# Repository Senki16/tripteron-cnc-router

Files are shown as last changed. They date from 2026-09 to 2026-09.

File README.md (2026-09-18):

# Tripteron CNC Router — 3-PRRR Parallel Machining Table

Design, drawings and complete engineering verification of a three-degree-of-freedom
translational parallel machine (Tripteron) used as a CNC router.

**IM0240 Machine Design I — Universidad EAFIT, Mechanical Engineering**

**Group 2:** David Amell Osorio · Ronny Antonio Bueno · Juan José García · Germán Gabriel Riaño Barrera · Sebastián Rincón Martínez · Juan Manuel Rodríguez Duque · David Zuluaga Henao
**Course lecturer:** Juan Andrés Gallego Sánchez
**Delivered:** 11 February 2024 (proposal) · 3 March 2024 (drawings) · 25 May 2024 (calculations)

<p align="center">
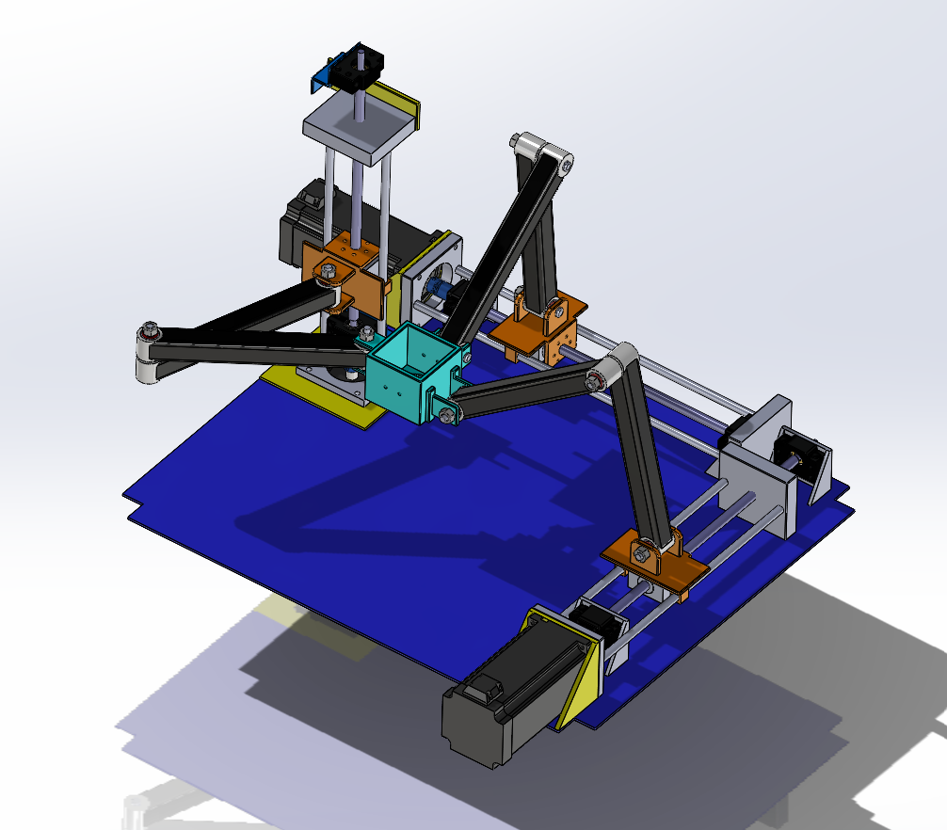
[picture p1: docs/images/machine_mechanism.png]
Tripteron mechanism: three PRRR legs on the work table
  
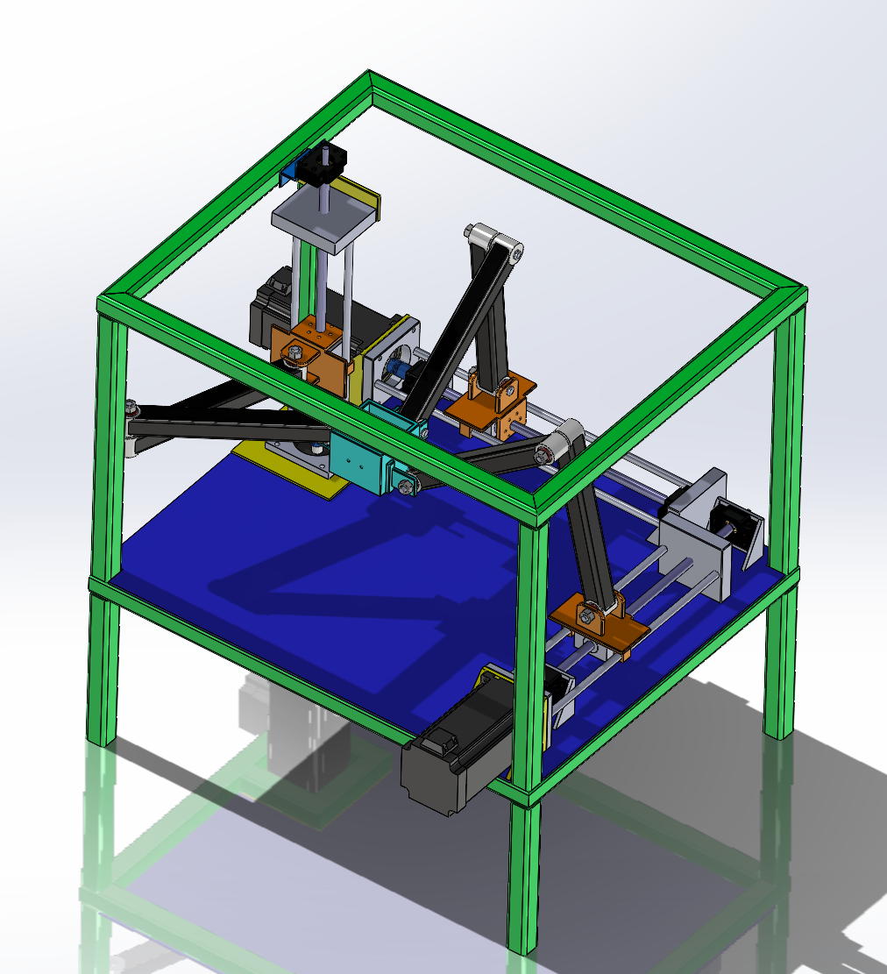
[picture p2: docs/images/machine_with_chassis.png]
Complete machine inside the welded chassis
  
</p>
<p align="center"><em>The 3-PRRR mechanism on the work table, and the complete machine inside its welded frame.</em></p>

---

## What this machine is

The Tripteron is a parallel manipulator with three identical **PRRR** legs: one prismatic
joint driven by a lead screw followed by three revolute joints with parallel axes. The
three prismatic axes are mutually orthogonal.

Its defining property is that it is **fully decoupled**: actuator *i* moves the tool along
axis *i* only, so the machine behaves like a cartesian router while being built as a
parallel mechanism. Its workspace is a perfect cube and its controller needs no coordinate
transformation. Both properties are proved numerically in the calculation report.

| Specification | Value |
|---|---|
| Degrees of freedom | 3 translations (no rotation) |
| Workspace | 200 mm cube — 8.615 dm³ |
| Link lengths | 240 mm (proximal and distal) |
| Stroke per axis | 200 mm |
| Feed rate | 10 mm/s |
| Cutting force (design) | [80, 80, −120] N |
| Drive | Ø8 mm trapezoidal lead screw, p = 2 mm, 4 starts (lead 8 mm) |
| Motor | NEMA 34 86HB250 closed loop, 4.5 N·m |
| Frame | Welded steel tube, alloy steel Sy = 620 MPa |

## Headline results

<p align="center">
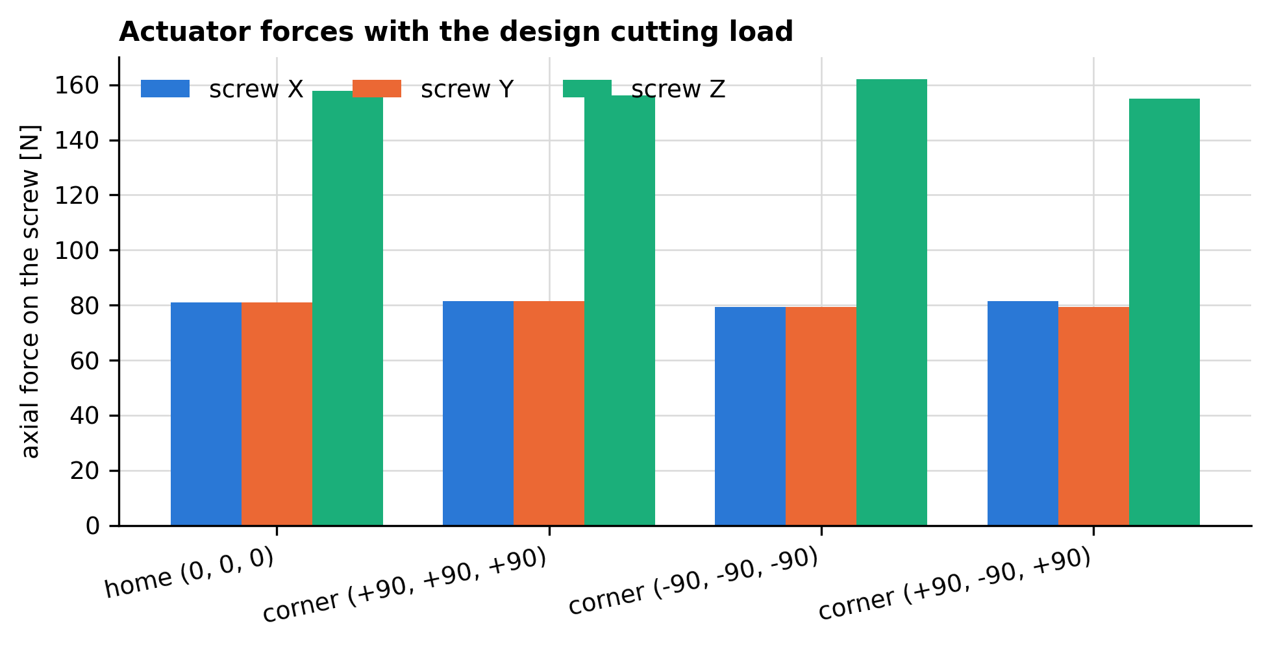
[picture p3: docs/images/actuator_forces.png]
Actuator forces across the workspace
  
</p>
<p align="center">
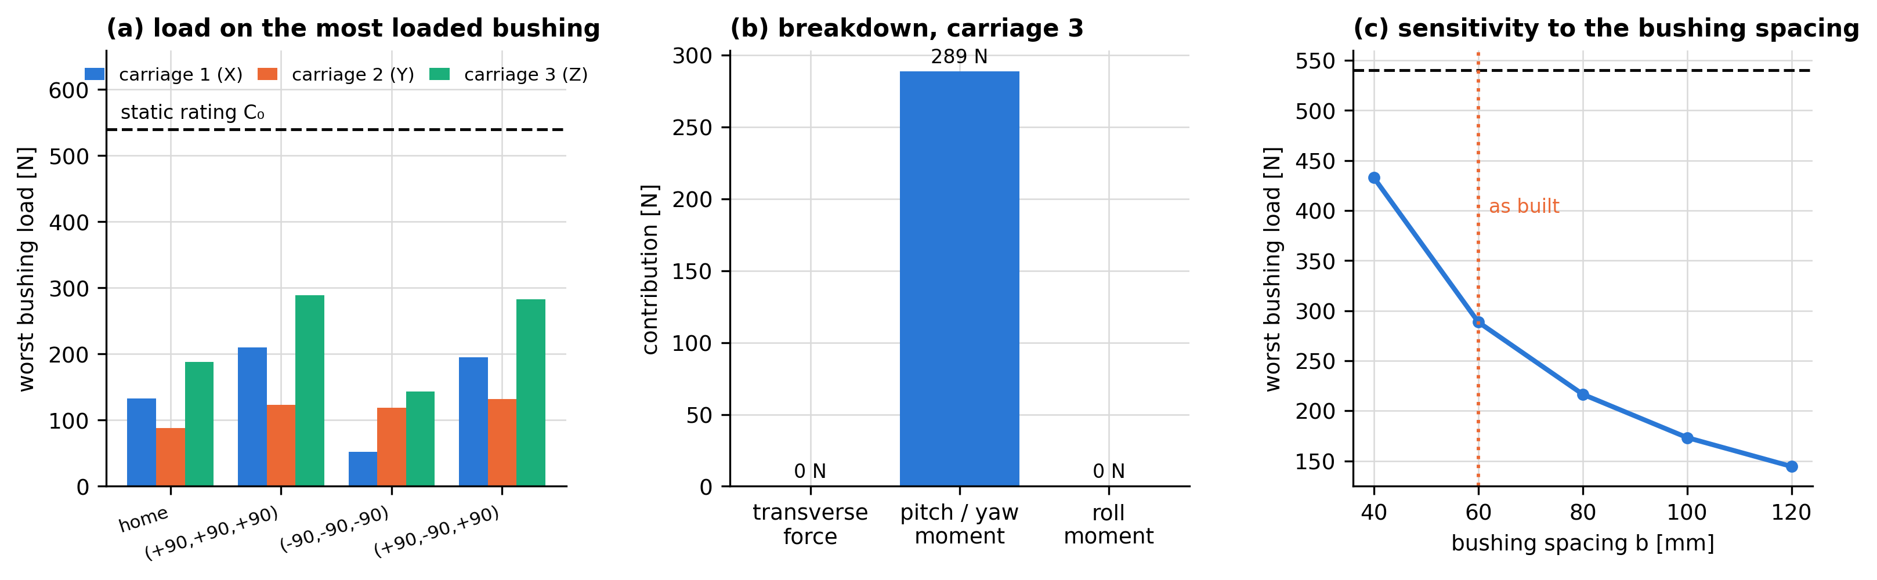
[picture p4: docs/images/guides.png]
Linear guide verification
  
</p>

| Verification | Result | Margin |
|---|---|---|
| Kinematic model | Newton–Raphson residual < 8·10⁻¹¹ mm | matches closed form to 10⁻¹³ mm |
| Design actuator load | **162.0 N** (worst pose, vertical axis) | varies only 4.5 % over the workspace |
| Arm bending stress | 26.1 MPa | SF 9.6 vs AISI 1020 |
| Lead screw, von Mises | 14.3 MPa | SF 25.8 |
| Lead screw, buckling | Pcr = 519.9 N (Euler) | **SF 3.21 — governing criterion** |
| Screw efficiency | 64.1 % | not self-locking → brake required on Z |
| Chassis FEA, stress | 9.36 MPa | SF 66 |
| Chassis FEA, deflection | 0.102 mm | the limiting number for accuracy |
| Guide bushings | 289 N on the worst bushing | **SF 1.87 — the tightest margin in the machine** |
| Guide rods | 8.7 MPa, 0.154 mm deflection | SF 40; more compliant than the whole frame |
| Chassis FEA, buckling | load factor 2238 | irrelevant at this load |

## Repository layout

```
01_Delivery1_Proposal/             Design proposal: requirements, PDS, architecture selection
02_Delivery2_Drawings/             Drawing package: English cover, index and the 35 drawing sheets
    sheets/                        the sheets as PNG (13 redrawn in English, 22 as issued)
03_Delivery3_Calculation_Report/   Calculation report: kinematics, statics, screw, FEA
04_Calculations/                   Python package that produces every number and figure
    tripteron/                     parameters, kinematics, statics, power_screw, fea_postprocess
    data/fea_exports/              nodal data exported from SolidWorks Simulation
    results/                       CSV + summary.json regenerated by run_all.py
    figures/                       PNG figures regenerated by run_all.py
05_CAD/
    Source_Models/                 SolidWorks parts, assemblies and drawings, by group
    Archives/                      large .zip/.rar exports (kept locally, not versioned)
06_Reference/                      Motor datasheets, component dimensions, course material
07_Media/                          Video of the machine running
docs/images/                       Images used by this README
```

## Reproducing the calculations

Everything in the calculation report is generated by code. From `04_Calculations/`:

```bash
python run_all.py
```

The script creates its own virtual environment on first run, installs the dependencies and
writes:

- `results/*.csv` and `results/summary.json` — every number quoted in the report
- `figures/*.png` — every figure of the report

### Modules

| Module | Contents |
|---|---|
| `tripteron/parameters.py` | All machine data in one place: geometry, masses, materials, loads |
| `tripteron/kinematics.py` | Loop-closure constraints, Jacobian, J̇, Newton–Raphson solver, closed-form inverse kinematics, trajectories, workspace |
| `tripteron/statics.py` | 60×63 rigid-body equilibrium system, minimum-norm solution, virtual-work actuator forces, arm stresses |
| `tripteron/power_screw.py` | Torque, efficiency, self-locking, stresses, Euler/Johnson column check |
| `tripteron/guides.py` | Bushing loads, rod stress and deflection of the carriages, sensitivity to the bushing spacing |
| `tripteron/fea_postprocess.py` | Post-processing of the SolidWorks Simulation exports |
| `run_all.py` | Runs the four studies and writes results and figures |

## License

Academic work produced for IM0240 at Universidad EAFIT, first semester 2024.
Shared for reference.

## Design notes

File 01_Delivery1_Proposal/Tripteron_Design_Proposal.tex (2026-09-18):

%==============================================================================
%  TRIPTERON - Delivery 1 : Design proposal (corrected English edition)
%  IM0240 Machine Design I - Universidad EAFIT
%==============================================================================
\documentclass[11pt]{article}
\usepackage[english]{babel}
\usepackage[utf8]{inputenc}
\usepackage{lmodern}
\usepackage[T1]{fontenc}
\usepackage{amsmath,amssymb,bm}
\usepackage{graphicx}
\usepackage{booktabs}
\usepackage{longtable}
\usepackage{array}
\usepackage{placeins}
\usepackage{lastpage}
\usepackage{enumitem}
\usepackage{siunitx}
\usepackage{tikz}
\usetikzlibrary{arrows.meta,positioning,shapes.geometric,calc}
\usepackage[table]{xcolor}
\usepackage[left=2.3cm,right=2.3cm,top=3.2cm,bottom=2.5cm]{geometry}
\usepackage{fancyhdr}
\usepackage[hidelinks]{hyperref}
\usepackage{titlesec}
\sisetup{detect-all, per-mode=symbol}

\definecolor{eafitblue}{HTML}{16436f}
\definecolor{lightgray}{HTML}{f0efe9}

\titleformat{\section}{\normalfont\large\bfseries\color{eafitblue}}{\thesection.}{0.6em}{}[{\titlerule[0.6pt]}]
\titleformat{\subsection}{\normalfont\normalsize\bfseries}{\thesubsection.}{0.6em}{}
\setlength{\parskip}{4pt}
\setlength{\parindent}{0pt}

\pagestyle{fancy}\fancyhf{}
\renewcommand{\headrulewidth}{0.4pt}
\fancyhead[L]{\small\textsc{Tripteron CNC router -- Design proposal}}
\fancyhead[R]{\small IM0240 Machine Design I}
\fancyfoot[C]{\small\thepage\ / \pageref{LastPage}}

\begin{document}

%------------------------------------------------------------------ cover
\thispagestyle{empty}
\begin{center}
\vspace*{1cm}
{\Large\scshape Universidad EAFIT}\\[3pt]
{\large School of Applied Sciences and Engineering}\\[3pt]
{\large Department of Mechanical Engineering}\\[3pt]
{\large IM0240 -- Machine Design I}\\[1.8cm]

{\color{eafitblue}\rule{\textwidth}{1.4pt}}\\[12pt]
{\huge\bfseries Design proposal for a}\\[6pt]
{\huge\bfseries CNC router machine}\\[10pt]
{\LARGE Tripteron 3-PRRR architecture}\\[10pt]
{\large\bfseries Delivery 1 -- Corrected English edition}\\[8pt]
{\color{eafitblue}\rule{\textwidth}{1.4pt}}\\[2cm]

{\large\bfseries Group 2}\\[8pt]
{\large David Amell Osorio}\\[4pt]
{\large Ronny Antonio Bueno}\\[4pt]
{\large Juan Jos\'e Garc\'ia}\\[4pt]
{\large Germ\'an Gabriel Ria\~no Barrera}\\[4pt]
{\large Sebasti\'an Rinc\'on Mart\'inez}\\[4pt]
{\large Juan Manuel Rodr\'iguez Duque}\\[4pt]
{\large David Zuluaga Henao}\\[1.4cm]

{\large\bfseries Course lecturer}\\[8pt]
{\large Juan Andr\'es Gallego S\'anchez}

\vfill
{\large Medell\'in, Colombia -- 11 February 2024}
\end{center}

\clearpage
\tableofcontents
\clearpage

%==============================================================================
\section{Introduction}
%==============================================================================

Within the Machine Design course, the assignment is to conceive, design and build a CNC
router that satisfies a specific set of technical requirements. The goal is a machine
that, using the concepts studied in the course, can be adapted to the manufacturing
processes where light routing and engraving are needed.

This document is the first delivery of the project. It defines the problem, surveys the
state of the art, establishes the requirements and the product design specification,
compares the mechanism architectures that could satisfy them and justifies the
architecture that was selected: a \textbf{Tripteron}, a three-degree-of-freedom
translational parallel machine with three PRRR legs actuated by power screws.

This is a corrected and restructured English edition of the original proposal. The
technical content of the original has been preserved; the errors identified in it are
listed and corrected in Section~\ref{sec:corrections}.

%==============================================================================
\section{Brief}
%==============================================================================

\subsection{What is a router machine?}

A CNC router is an automated machine that uses computer numerical control to cut, carve or
engrave materials such as wood, plastic, metal and composites. It works with a rotating
cutting tool --- an end mill --- whose path is controlled by a program. Because the
process is both precise and repeatable, routers are a basic tool in manufacturing and
design workshops.

\subsection{How does it work?}

The tool moves in a three-dimensional coordinate system driven by three motors. The
operator's controller commands the motors so that the tool sweeps the programmed path
inside the working volume. Each motor drives one power screw, and each power screw moves
one axis of the machine.

\subsection{Which materials are viable for its construction?}

Different parts call for different materials:

\begin{center}
\begin{tabular}{@{}l>{\raggedright\arraybackslash}p{4.0cm}>{\raggedright\arraybackslash}p{8.4cm}@{}}
\toprule
\textbf{Part} & \textbf{Material} & \textbf{Reason} \\
\midrule
External enclosure & PVC or wood & Carries no significant load; low cost, easy to shape \\
Structural frame   & Steel or aluminium & Carries the machining loads and the weight of the drives \\
Mechanism (links, screws) & Steel & Stiffness and wear resistance govern the accuracy \\
\bottomrule
\end{tabular}
\end{center}

%==============================================================================
\section{Objectives}
%==============================================================================

\subsection{General objective}

Design and build a numerically controlled router able to cut at least \SI{1}{\milli\metre}
of depth in a range of materials, making the best use of the available materials,
manufacturing processes and aesthetics.

\subsection{Specific objectives}

\begin{itemize}[leftmargin=*]
  \item Define the flows through the machine --- the inputs it needs and the outputs it
        must deliver --- so that the concept is built on a solid functional basis.
  \item Develop a support structure that guarantees stable operation, minimising
        vibration and avoiding buckling under the weight of the equipment.
  \item Design a machine that meets the client's expectations in appearance, design and
        aesthetics, so that the result is attractive from the user's point of view.
  \item Plan the specific requirements needed to satisfy the client, ensuring the
        technical and functional feasibility of the project.
  \item Select a kinematic chain and a mechanism that suit both the client's needs and an
        efficient development process, guaranteeing adequate performance.
\end{itemize}

%==============================================================================
\section{State of the art}
%==============================================================================

\subsection{CNC machines}

A CNC (computer numerical control) machine removes the human factor from the trajectory of
the tool: the cut is performed automatically by a computer that feeds numerical
coordinates to the machine, which is what makes millimetre and sub-millimetre precision
repeatable.

\subsection{Motion control}

The motion of a CNC machine is controlled by software that interprets G-code. The general
process is:

\begin{enumerate}[leftmargin=*]
  \item \textbf{Model design.} The part is modelled in 3D with a CAD package.
  \item \textbf{G-code generation.} A CAM package converts the model into the G-code that
        specifies tool movements, cutting speeds and tooling.
  \item \textbf{Transfer.} The program is transferred to the machine over a USB drive or a
        network connection.
  \item \textbf{Set-up.} The tool is mounted, the stock is clamped and the cutting
        parameters --- feed rate and spindle speed --- are configured.
  \item \textbf{Execution.} The controller interprets the G-code and moves the axes
        accordingly, producing the part.
\end{enumerate}

\subsection{The CNC program}

A CNC program is a set of coded instructions written mainly in G-code, complemented by M,
S and T codes depending on the functions the machine offers.

\subsection{Types of CNC machines}

\begin{center}
\begin{tabular}{@{}l>{\raggedright\arraybackslash}p{10.7cm}@{}}
\toprule
\textbf{Criterion} & \textbf{Classes} \\
\midrule
By function & Milling machines, lathes, drilling machines, plasma cutters, grinders. \\
By motion   & \emph{Point to point}: the stock and the tool are positioned and held while
              the cutter completes the operation, then retracted.
              \emph{Contouring}: the tool follows the contour of the part along a
              continuous path. \\
By number of axes & 2 axes; 2.5 axes (the three axes move, but $x$ and $y$ position first
              and only then does $z$ work); 3 axes; 4 axes (3 axes plus one rotation,
              $A$ or $B$); 5 axes (3 axes plus two rotations, $A$ and $B$). \\
\bottomrule
\end{tabular}
\end{center}

The machine of this project is a \textbf{3-axis contouring router}.

\subsection{Applications}

Manufacture of metal and plastic parts; cutting and engraving of wood, metal, plastic and
stone for signage, architectural models and artistic engraving; prototyping and mass
production of identical parts; medical devices, prostheses and surgical instrument
components; and, on machines equipped for it, additive manufacturing.

\subsection{Key components}

\begin{description}[leftmargin=0pt,style=nextline]
  \item[Power screw] A mechanical device that converts rotary into linear motion. A
        threaded screw engages a nut with an internal thread; turning the screw
        translates the nut along its axis. It is the element that turns the rotation of
        the motor into the feed of the axis, and it is sized in Delivery~3.
  \item[NEMA 34 stepper motor] A NEMA standard frame size, roughly \SI{86}{\milli\metre}
        across the body, known for high torque. It is used in industrial CNC machines,
        large-format 3D printers and automation equipment. The closed-loop 86HB250 variant
        selected for this project delivers \SI{4.5}{\newton\metre} of holding torque.
  \item[End mill] The rotating cutting tool. A sharpened metal tip turns at high speed and
        removes material on contact. End mills are interchangeable and are chosen
        according to the material and the finish required.
\end{description}

%==============================================================================
\section{User definition}
%==============================================================================

The user of the router is someone experienced with cutting equipment who is looking for a
versatile, easy to operate and affordable machine. The intended duty is light cutting
without extreme demands, in a workshop with a mains supply. The machine is to be operated
by people of at least 18 years of age.

%==============================================================================
\section{Conceptual design}
%==============================================================================

\subsection{Requirements imposed by the course}

\begin{itemize}[leftmargin=*,nosep]
  \item A cutting machine (router) with \textbf{3 degrees of freedom}.
  \item The machine \textbf{may not} be a cartesian system built from prismatic pairs in
        series.
  \item The degrees of freedom must be \textbf{coupled}, i.e.\ the architecture must be a
        parallel one.
  \item The prismatic pairs must be \textbf{actuated by power screws}.
  \item The machine may be spatial (linear delta or Tripteron) or planar.
  \item It must be able to cut at least \SI{1}{\milli\metre} deep in aluminium, copper,
        brass or nylon.
\end{itemize}

\subsection{Technical design requirements}

\begin{center}
\begin{tabular}{@{}l>{\raggedright\arraybackslash}p{10.4cm}@{}}
\toprule
\textbf{Requirement} & \textbf{Definition} \\
\midrule
Feed rate   & Constant routing speed of approximately \SI{10}{\milli\metre\per\second}. \\
Accuracy    & Path error not greater than \SI{1}{\milli\metre}. \\
Cutting capability & Able to route wood, aluminium, copper, brass and nylon to a depth of at least \SI{1}{\milli\metre}. \\
Safety      & The machine must not put the operator at risk during operation. \\
Control     & The operator must have buttons or instruments to start and stop the process. \\
Energy and information & The machine must carry a control system that transmits accurate
              process information while a stable power supply is guaranteed. \\
\bottomrule
\end{tabular}
\end{center}

\subsection{Black box}

The black box states \emph{what} the machine does without saying \emph{how}: the three
flows --- material, energy and information --- that cross its boundary.

\begin{figure}[htbp]\centering
\begin{tikzpicture}[font=\small,node distance=6mm,
  flow/.style={-{Latex[length=2.5mm]},thick}]
\node[draw,fill=lightgray,minimum width=5.4cm,minimum height=3.2cm,align=center,
      rounded corners=2pt,thick] (bb)
      {\bfseries Route the\\\bfseries workpiece};
\node[left=3.0cm of bb.west,anchor=east,align=right] (in) {};
\draw[flow] ($(bb.west)+(-3.0,0.9)$) -- node[above,font=\scriptsize]{raw stock} ($(bb.west)+(0,0.9)$);
\draw[flow] ($(bb.west)+(-3.0,0.0)$) -- node[above,font=\scriptsize]{electrical energy} ($(bb.west)+(0,0.0)$);
\draw[flow] ($(bb.west)+(-3.0,-0.9)$) -- node[above,font=\scriptsize]{part program (G-code)} ($(bb.west)+(0,-0.9)$);
\draw[flow] ($(bb.east)+(0,0.9)$) -- node[above,font=\scriptsize]{routed part} ($(bb.east)+(3.0,0.9)$);
\draw[flow] ($(bb.east)+(0,0.0)$) -- node[above,font=\scriptsize]{chips, heat, noise} ($(bb.east)+(3.0,0.0)$);
\draw[flow] ($(bb.east)+(0,-0.9)$) -- node[above,font=\scriptsize]{process status} ($(bb.east)+(3.0,-0.9)$);
\end{tikzpicture}
\caption{Black box of the router: material, energy and information flows.}
\end{figure}

\subsection{Functional structure}

The functional structure --- the ``transparent box'' --- decomposes the overall function
into the elementary functions that the machine must perform, which is what allows the
concept to be generated function by function instead of by copying an existing machine.

\begin{figure}[htbp]\centering
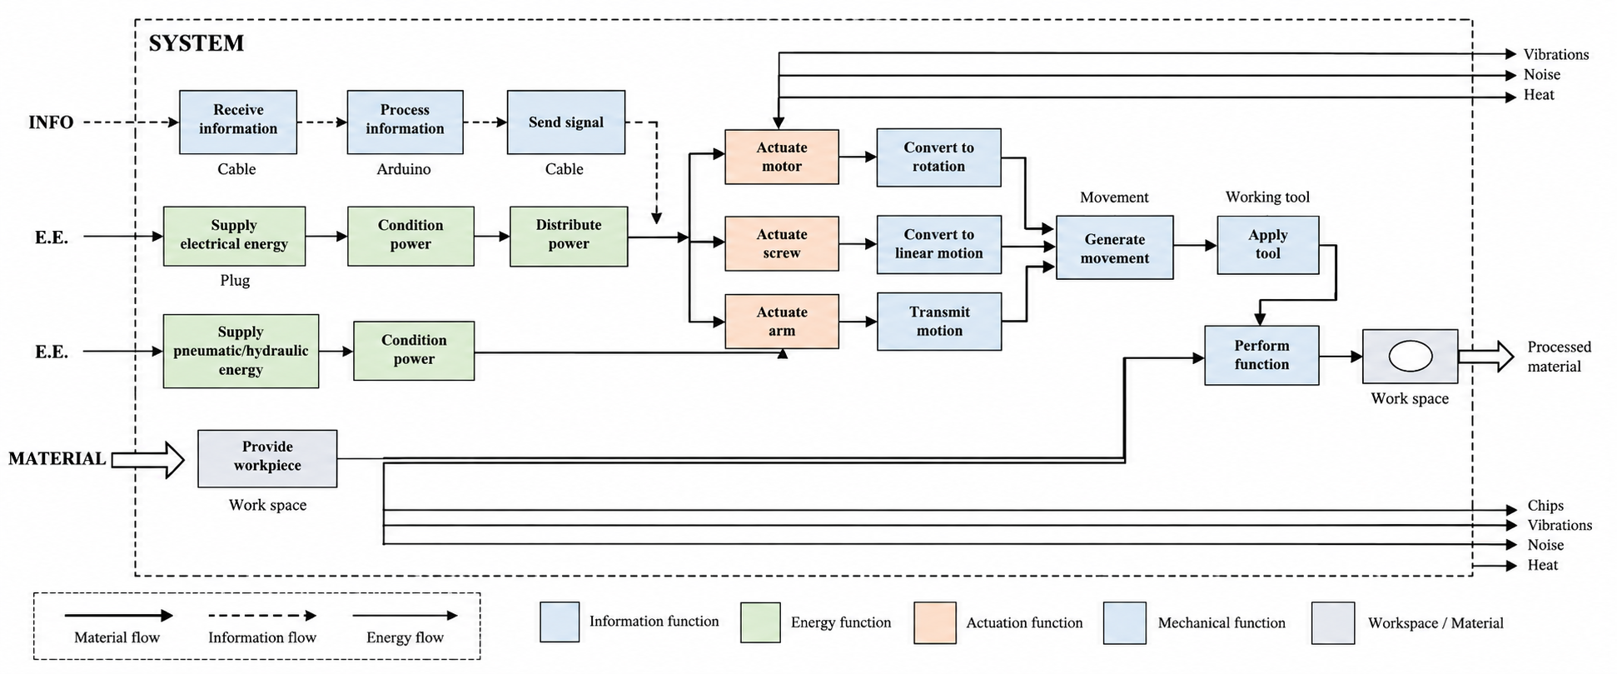
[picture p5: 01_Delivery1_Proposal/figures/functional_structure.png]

\caption{Functional structure of the machine: the material, energy and information flows
and the elementary functions that transform them.}
\end{figure}
\FloatBarrier

\subsection{Attributes}

The attributes are the measurable quantities through which each flow is evaluated in the
product design specification.

\begin{center}
\begin{tabular}{@{}llll@{}}
\toprule
\textbf{Material} & \textbf{On/off} & \textbf{Manual work} & \textbf{Energy} \\
\midrule
Strength        & Production accuracy & Accuracy            & Transfer \\
Specific weight & Power required      & Instructions        & Voltage \\
Size            &                     & Ease of production  & Current \\
Thickness       &                     &                     & Power \\
\bottomrule
\end{tabular}
\end{center}

\subsection{Product design specification (PDS)}

\begin{center}\small
\begin{tabular}{@{}cl l r l c c@{}}
\toprule
\textbf{\#} & \textbf{Requirement} & \textbf{Metric} & \textbf{Value} & \textbf{Unit} & \textbf{Weight} & \textbf{D/d} \\
\midrule
1  & Degrees of freedom      & Coupled DOF        & 3       & DOF        & 4 & D \\
2  & Service life            & Time               & 3       & h          & 4 & d \\
3  & Ease of assembly        & Time               & $<3$    & h          & 4 & D \\
4  & Ease of maintenance     & Time               & 2       & h          & 4 & d \\
5  & Cost                    & Money              & 500\,000& COP        & 5 & D \\
6  & Construction time       & Time               & 3       & months     & 4 & d \\
7  & Width                   & Length             & 0.55    & m          & 5 & d \\
8  & Depth                   & Length             & 0.55    & m          & 5 & d \\
9  & Height                  & Length             & 0.55    & m          & 5 & d \\
10 & Feed rate               & Speed              & 10      & mm/s       & 3 & D \\
11 & Path accuracy           & Length             & $\le 1$ & mm         & 5 & D \\
12 & Depth of cut            & Length             & $\ge 1$ & mm         & 5 & D \\
13 & Emergency stop response & Time               & 0.5     & s          & 6 & D \\
14 & Positioning resolution  & Length             & 0.1     & mm         & 7 & D \\
\bottomrule
\end{tabular}
\end{center}
{\footnotesize D = demand (must be met), d = desire (desirable). The units of rows 10--14
were corrected with respect to the original proposal; see
Section~\ref{sec:corrections}.}

\subsection{Morphological matrix}

Each elementary function of the functional structure was given a set of possible
solutions, and the concepts were generated by combining one solution per function.

\begin{figure}[htbp]\centering
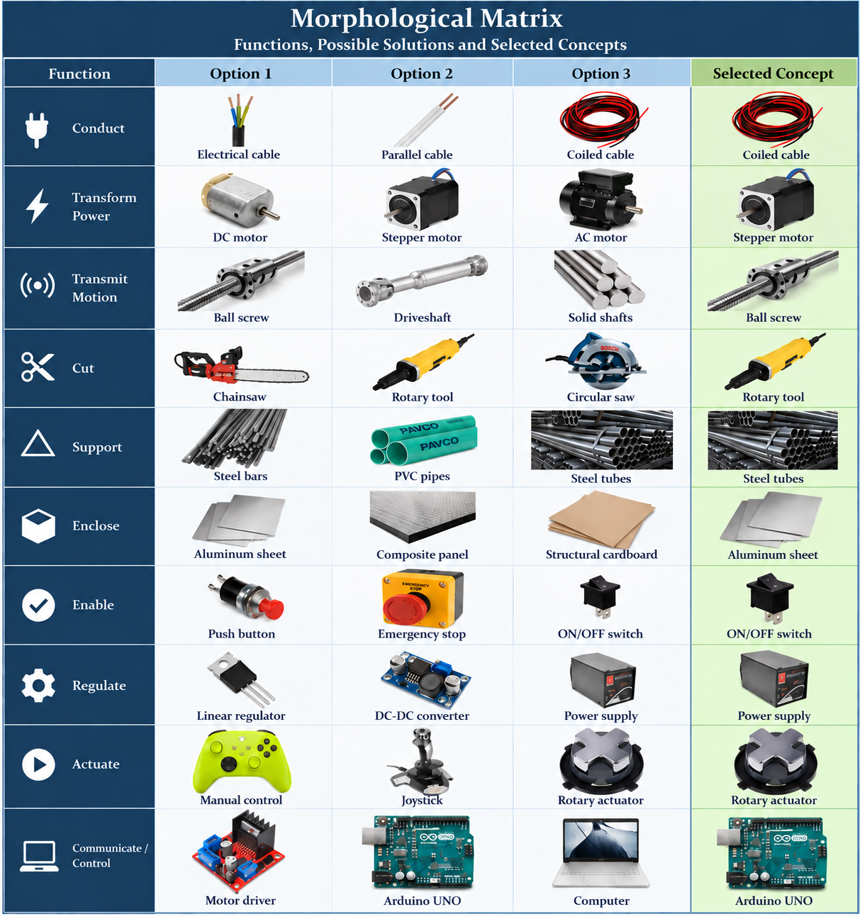
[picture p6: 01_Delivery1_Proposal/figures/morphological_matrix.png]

\caption{Morphological matrix: for every function, the solutions considered and the one
selected.}
\end{figure}
\FloatBarrier

The concept finally built follows this matrix in everything except the transmission: the
matrix selects a ball screw, and what was fitted is a trapezoidal lead screw
(Tr8$\times$8, four starts), which is cheaper and self-supporting in the nut but far less
efficient. Delivery~3 quantifies that choice: \SI{64.1}{\percent} efficiency and no
self-locking.

\subsection{Evaluation matrix}

Each member scored the individual concepts against the technical requirements of the PDS;
the concept with the highest weighted score was taken as the basis of the final one.

\begin{figure}[htbp]\centering
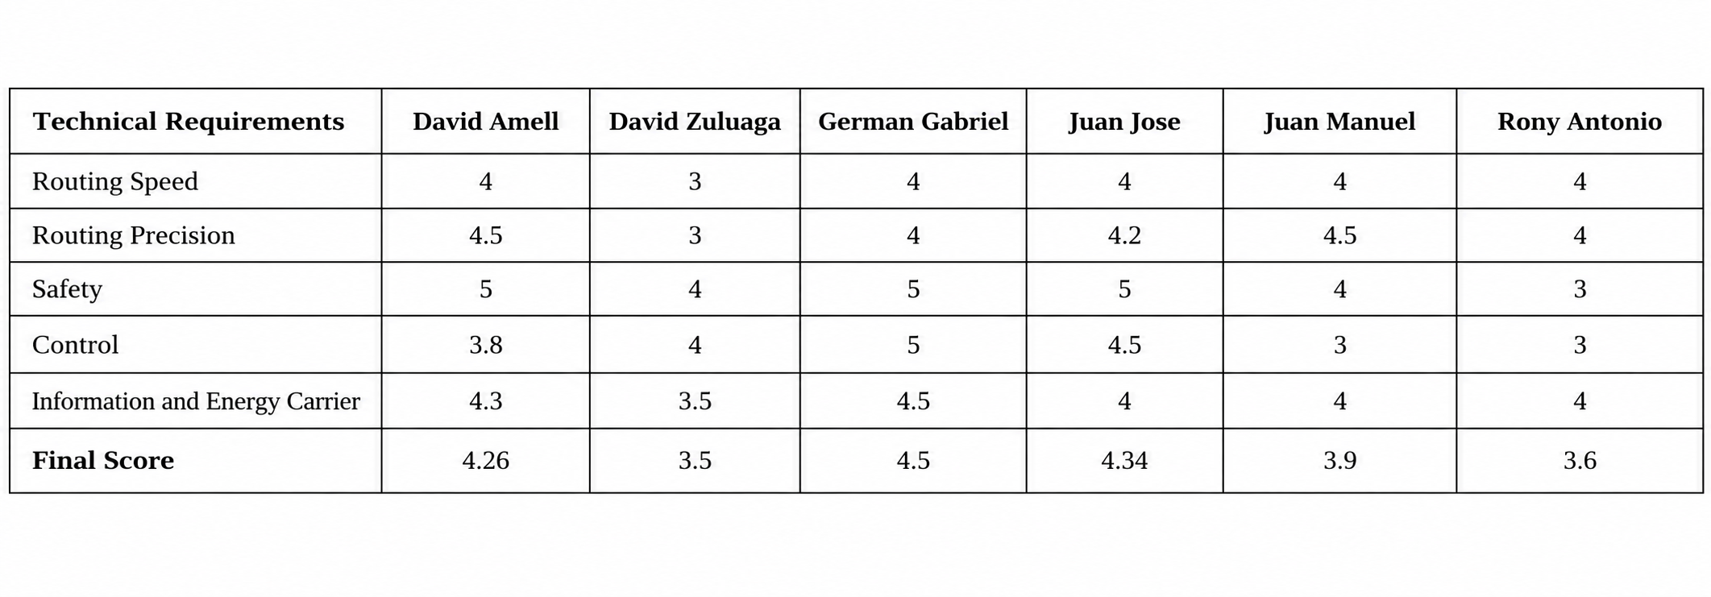
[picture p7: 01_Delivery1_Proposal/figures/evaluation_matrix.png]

\caption{Evaluation matrix of the individual concepts against the technical requirements.}
\end{figure}
\FloatBarrier

The highest score went to the concept of Germ\'an Gabriel Ria\~no (4.5), followed by Juan
Jos\'e Garc\'ia (4.34) and David Amell (4.26). The final concept keeps the frame and axis
layout of the first and the tool mounting of the others.

The evaluation against the PDS selected: stepper motors, power screws, linear guides, a
welded steel frame, a microcontroller-based controller, and the \textbf{Tripteron}
architecture.

%==============================================================================
\section{Mechanism architecture}
%==============================================================================

\subsection{Topological synthesis}

\begin{description}[leftmargin=0pt,style=nextline]
  \item[Base] The fixed frame. It does not move while the machine is operating and it
        carries the three guides, the three screws and the work table.
  \item[Arms] Three identical legs. Each leg is driven along one axis and transmits that
        motion to the platform through two links and three parallel revolute joints.
  \item[Cutting tool] Mounted on the platform where the three legs meet. It performs the
        milling, drilling or cutting work.
\end{description}

\subsection{Mobility}

The machine has 10 moving bodies --- three carriages, six links and the platform --- and
12 joints, each with one degree of freedom (3 prismatic and 9 revolute). The
Kutzbach--Gr\"ubler criterion for spatial mechanisms gives
\begin{equation}
M = 6\,(n_b) - \sum_{i}(6-f_i) = 6\times10 - 12\times5 = 0 ,
\end{equation}
where $n_b=10$ is the number of moving bodies and $f_i=1$ for every joint.

The formula predicts a structure, yet the machine moves with three degrees of freedom.
The discrepancy is not an error: the Tripteron belongs to the family of
\textbf{over-constrained} mechanisms, in which the special geometry --- the three revolute
axes of each leg parallel to one another and perpendicular to its prismatic axis ---
makes three of the 60 constraint equations redundant. The true mobility is therefore
\begin{equation}
M = 0 + 3 = 3 \quad\text{translations, no rotation.}
\end{equation}
Exactly the same number of redundancies appears again in Delivery~3, where the static
equilibrium system turns out to have 63 unknowns and rank 60. The two analyses are
consistent, and the consequence for manufacturing is important: an over-constrained
machine is sensitive to assembly errors, so the parallelism and squareness tolerances of
the three guides must be tight.

\subsection{Why a Tripteron}

\begin{center}
\begin{tabular}{@{}l>{\raggedright\arraybackslash}p{5.2cm}>{\raggedright\arraybackslash}p{5.2cm}@{}}
\toprule
\textbf{Architecture} & \textbf{Advantages} & \textbf{Disadvantages} \\
\midrule
Serial cartesian & Simple, decoupled, cubic workspace &
                   \textbf{Not allowed by the course}; each axis carries the next \\
Linear delta     & Light moving mass, fast &
                   Coupled kinematics, curved workspace boundary, singularities inside
                   the useful volume \\
\textbf{Tripteron} & \textbf{Decoupled} like a cartesian machine but built as a parallel
                   mechanism; cubic workspace; actuators fixed to the frame; simple
                   controller &
                   Over-constrained, so it demands accurate assembly; more links than a
                   delta \\
\bottomrule
\end{tabular}
\end{center}

The Tripteron was selected because it satisfies the course requirement of coupled,
parallel architecture while keeping the two practical advantages of a cartesian machine:
a cubic workspace and a controller that needs no coordinate transformation. Delivery~3
confirms both properties numerically.

%==============================================================================
\section{Concept proposals}
%==============================================================================

Each member of the team developed an individual concept; the concepts were then compared
against the PDS and merged into a single final concept.

\begin{figure}[htbp]\centering
\begin{minipage}[t]{0.24\textwidth}\centering
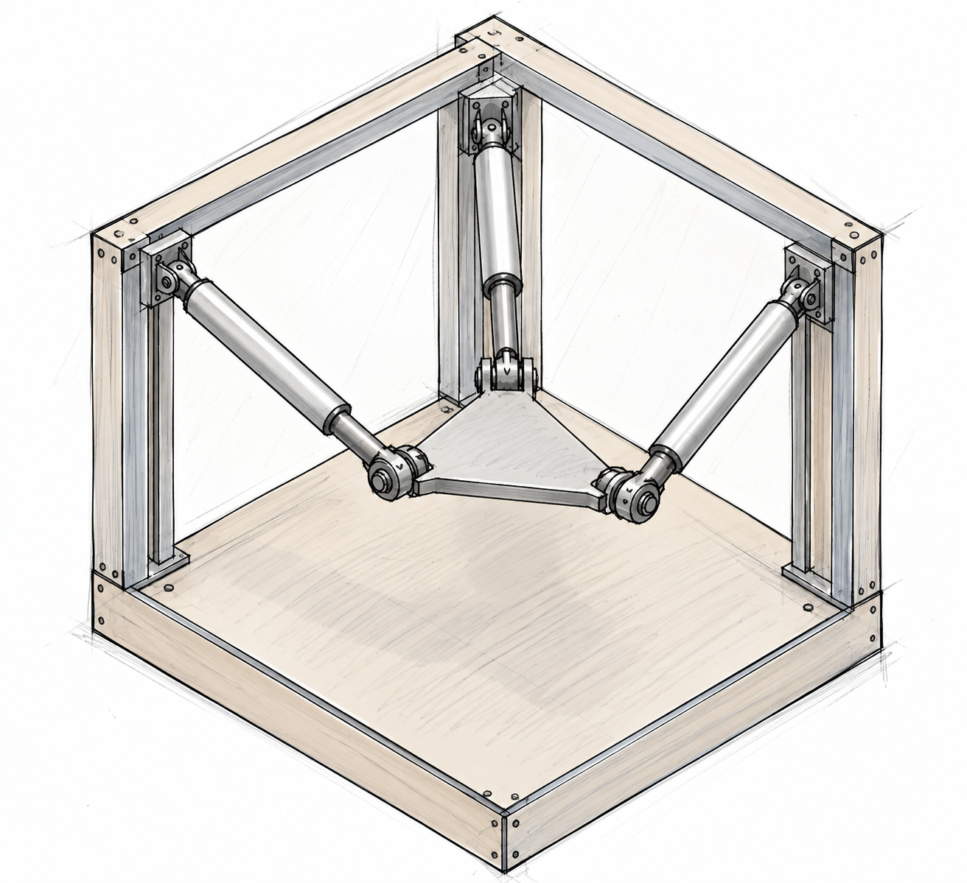
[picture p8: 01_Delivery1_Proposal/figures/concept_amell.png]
\\[4pt]{\footnotesize David Amell Osorio}
\end{minipage}\hfill
\begin{minipage}[t]{0.24\textwidth}\centering
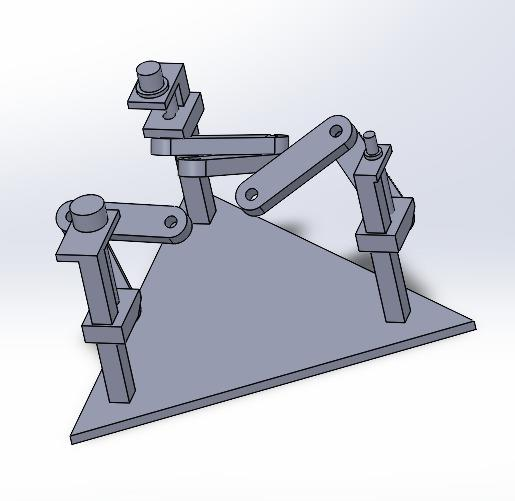
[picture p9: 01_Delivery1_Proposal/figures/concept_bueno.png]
\\[4pt]{\footnotesize Ronny Antonio Bueno}
\end{minipage}\hfill
\begin{minipage}[t]{0.24\textwidth}\centering
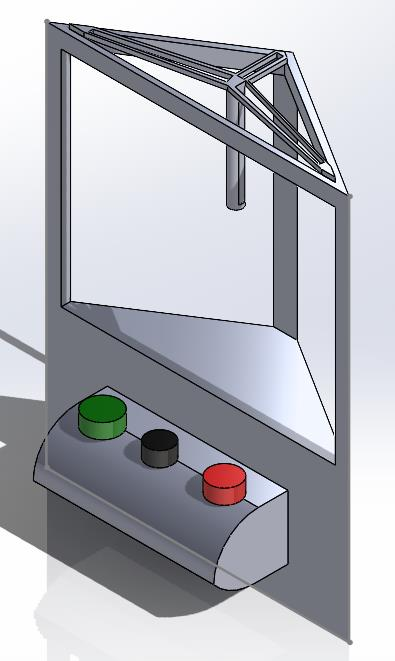
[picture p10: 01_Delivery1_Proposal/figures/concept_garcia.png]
\\[4pt]{\footnotesize Juan Jos\'e Garc\'ia}
\end{minipage}\hfill
\begin{minipage}[t]{0.24\textwidth}\centering
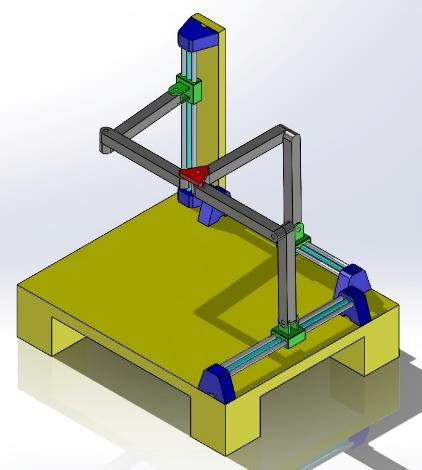
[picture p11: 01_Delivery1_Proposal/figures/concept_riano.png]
\\[4pt]{\footnotesize Germ\'an G. Ria\~no}
\end{minipage}

\vspace{10pt}

\begin{minipage}[t]{0.24\textwidth}\centering
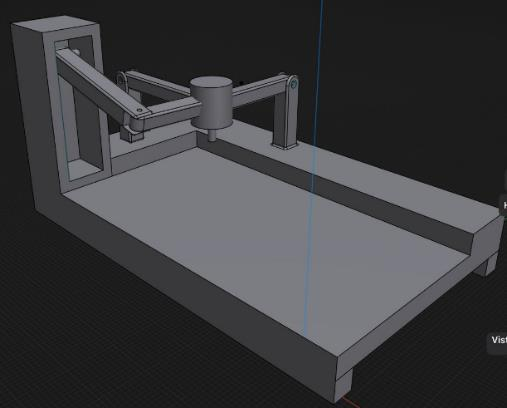
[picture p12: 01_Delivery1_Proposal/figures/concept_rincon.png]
\\[4pt]{\footnotesize Sebasti\'an Rinc\'on}
\end{minipage}\hfill
\begin{minipage}[t]{0.24\textwidth}\centering
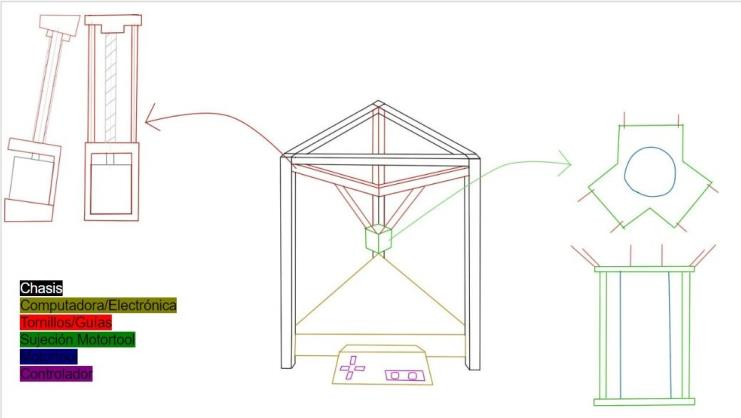
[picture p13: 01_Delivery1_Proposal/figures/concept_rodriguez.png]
\\[4pt]{\footnotesize Juan M. Rodr\'iguez}
\end{minipage}\hfill
\begin{minipage}[t]{0.24\textwidth}\centering
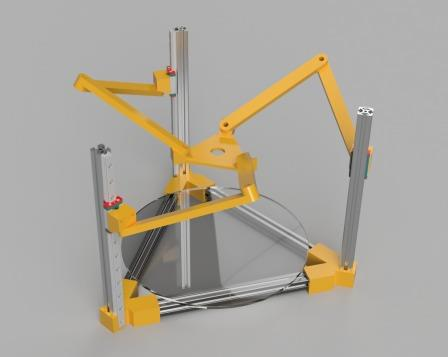
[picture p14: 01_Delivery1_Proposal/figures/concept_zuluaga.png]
\\[4pt]{\footnotesize David Zuluaga Henao}
\end{minipage}\hfill
\begin{minipage}[t]{0.24\textwidth}\centering
\rule{0pt}{3.0cm}
\end{minipage}
\caption{The seven individual concepts, one per member of the group.}
\end{figure}

\begin{figure}[htbp]\centering
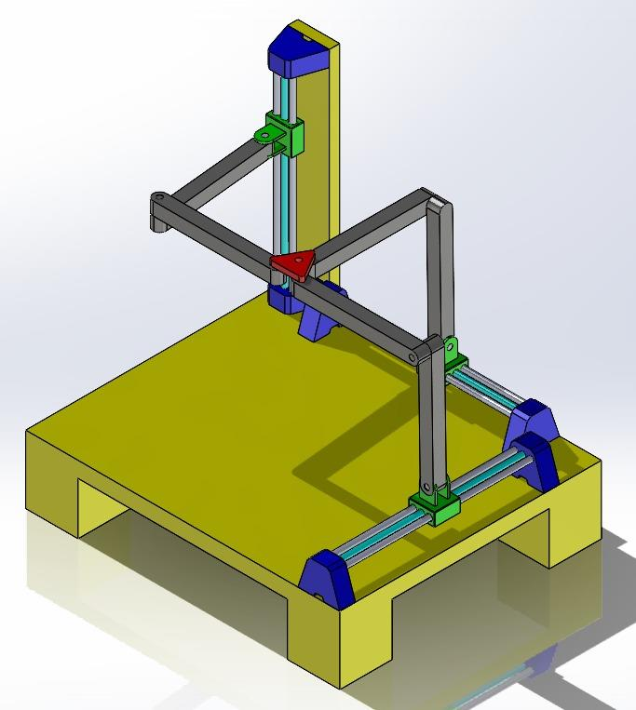
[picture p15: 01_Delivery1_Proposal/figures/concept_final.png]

\caption{Final concept: welded frame, three orthogonal screw-driven axes, Tripteron legs
and a spindle mounted on the moving platform.}
\end{figure}
\FloatBarrier

The final concept keeps the vertical axis on a column at the rear of the frame and the two
horizontal axes along the base, so that the three screws are all mounted on the fixed
structure and no motor travels with the tool. The work table is fixed, which removes the
need to accelerate the workpiece.

%==============================================================================
\section{Work methodology}
%==============================================================================

The CNC router is developed as a collaborative effort in which every member of the group
contributes ideas and knowledge. The drawing package is produced jointly, so that
different points of view and experience are integrated into it. The construction of the
machine --- enclosure, structure and mechanism --- is carried out by specialised
sub-groups whose work is then merged in an integration process that ends on 24 May.

Every week the group meets to agree on the tasks to be developed next and to report on
the ones already completed. Working together is what keeps the process on track.

\subsection{Planned dates}

\begin{center}
\begin{tabular}{@{}llll@{}}
\toprule
\textbf{29 July} & \textbf{12 August} & \textbf{16 September} & \textbf{28 October} \\
\midrule
Concept delivery & Drawing delivery & Model delivery & Calculation delivery \\
\bottomrule
\end{tabular}
\end{center}

\subsection{Distribution of the work}

\begin{center}
\begin{tabular}{@{}l>{\raggedright\arraybackslash}p{9.4cm}@{}}
\toprule
\textbf{Member} & \textbf{Responsibility} \\
\midrule
David Amell Osorio        & Tool support, final assembly drawings, kinematic analysis \\
Ronny Antonio Bueno       & Arms and R-pair system, guide calculations \\
Juan Jos\'e Garc\'ia      & Electrical system and wiring, lead-screw calculations \\
Germ\'an G. Ria\~no Barrera & Chassis and guide system, drawings, lead-screw and guide calculations \\
Sebasti\'an Rinc\'on Mart\'inez & Static analysis \\
Juan Manuel Rodr\'iguez Duque   & Guide system drawings, static analysis \\
David Zuluaga Henao       & Kinematics, finite element analysis of the chassis, spacers \\
\bottomrule
\end{tabular}
\end{center}

%==============================================================================
\section{Planned calculations}
%==============================================================================

\begin{itemize}[leftmargin=*,nosep]
  \item A \textbf{kinematic analysis} to obtain the position, velocity and acceleration of
        every body of the machine, and to establish the workspace.
  \item A \textbf{static analysis} to identify the forces on the actuators, the joints and
        the links.
  \item A \textbf{solid mechanics} verification to confirm that the selected materials
        withstand those forces --- in particular the power screws, which are slender and
        loaded in compression.
  \item A \textbf{finite element analysis} of the frame, whose redundant three-dimensional
        structure cannot be resolved by hand.
\end{itemize}

All four were carried out and are reported in Delivery~3.

%==============================================================================
\section{Conclusions}
%==============================================================================

\begin{enumerate}[leftmargin=*]
  \item A Tripteron was selected over a linear delta because it is the only parallel
        architecture that keeps the decoupled behaviour and the cubic workspace of a
        cartesian machine, which simplifies both the control and the programming of the
        part.
  \item The design must be optimised for material usage and cost: the PDS sets a budget of
        COP 500\,000 and an overall size of \SI{0.55}{\metre} per side, and both are
        binding constraints on the frame.
  \item The mobility analysis shows that the machine is over-constrained. This is
        acceptable, but it converts the parallelism of the three guides into a critical
        manufacturing tolerance, and it must be watched during assembly.
  \item The kinematic analysis is required before the structure can be dimensioned, since
        the stroke of each screw and the length of the links determine the size of the
        frame.
\end{enumerate}

%==============================================================================
\section{Corrections with respect to the original proposal}\label{sec:corrections}
%==============================================================================

\begin{center}
\begin{tabular}{@{}c>{\raggedright\arraybackslash}p{4.6cm}>{\raggedright\arraybackslash}p{5.2cm}>{\raggedright\arraybackslash}p{4.2cm}@{}}
\toprule
\textbf{\#} & \textbf{Original} & \textbf{Problem} & \textbf{Correction} \\
\midrule
1 & Mobility computed as $M=3n-2J_1-J_2=3$
  & That is Gr\"ubler's formula for \emph{planar} mechanisms; the Tripteron is spatial.
  & Kutzbach for spatial mechanisms, $M=6n_b-\sum(6-f_i)=0$, plus 3 redundant constraints
    $\Rightarrow M=3$ \\
2 & ``3 DOF: rotation about the base ($z$) and horizontal motion''
  & The Tripteron platform does not rotate; its three degrees of freedom are pure
    translations.
  & 3 translations $x$, $y$, $z$; zero rotations \\
3 & Feed rate listed as ``300 millimetres'' with the metric ``distance''
  & A feed rate is a speed, not a distance; the value contradicted the
    \SI{10}{\milli\metre\per\second} stated in the text.
  & \SI{10}{\milli\metre\per\second} \\
4 & Accuracy listed as ``85 percent''
  & Accuracy of a machine tool is a length, not a percentage.
  & Path error $\le\SI{1}{\milli\metre}$ \\
5 & Cutting capability listed as ``10 cm/s$^2$'', metric ``area/time$^2$''
  & Neither the unit nor the metric corresponds to a depth of cut.
  & Depth of cut $\ge\SI{1}{\milli\metre}$ \\
6 & Service life of 3 hours
  & Three hours is a test duration, not a service life.
  & Retained as stated, but reinterpreted as continuous operating time between maintenance
    stops \\
7 & Section numbering out of step (section 3 containing subsections 4.1, 4.2, \dots)
  & Made cross-referencing impossible.
  & Numbering rebuilt \\
8 & Repeated figures and an unattributed image taken from the internet
  & Duplicated content and unreferenced third-party material.
  & Duplicates removed; only the group's own material is reproduced \\
9 & Planned dates of 29 July, 12 August, 16 September and 28 October
  & They belong to a different semester's calendar: this proposal is dated 11 February
    2024 and the project ran from February to May 2024.
  & The table is kept as submitted; the dates actually met were 11 February (proposal),
    3 March (drawings) and 25 May 2024 (calculations) \\
\bottomrule
\end{tabular}
\end{center}

%==============================================================================
\section{References}
%==============================================================================

\begin{enumerate}[leftmargin=*,nosep]
  \item Gosselin, C.\ et al.\ \textit{The Tripteron: a new 3-DOF translational parallel
        mechanism}. Universit\'e Laval.
  \item RepRap Wiki. \textit{Tripteron}. \url{https://reprap.org/wiki/Tripteron}
  \item O'Connell, J. \textit{Tripteron 3D Printer: All You Need to Know}. All3DP, 2021.
  \item Budynas, R.\ and Nisbett, K. \textit{Shigley's Mechanical Engineering Design},
        10th ed., McGraw-Hill. Chapter 8: power screws.
  \item SIDECO. \textit{\textquotedblleft Qu\'e son las m\'aquinas CNC\textquotedblright}.
        \url{https://sideco.com.mx/que-son-las-maquinas-cnc/}
  \item Aeromaquinados. \textit{M\'aquina CNC}.
        \url{https://aeromaquinados.com/maquina-cnc/}
\end{enumerate}

\end{document}

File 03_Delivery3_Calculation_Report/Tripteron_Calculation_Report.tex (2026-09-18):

%==============================================================================
%  TRIPTERON - 3-PRRR PARALLEL MACHINE
%  Delivery 3 : Calculation report (corrected and recomputed edition)
%  Machine Design I - Universidad EAFIT
%==============================================================================
\documentclass[11pt]{article}
\usepackage[english]{babel}
\usepackage[utf8]{inputenc}
\usepackage{lmodern}
\usepackage[T1]{fontenc}
\usepackage{amsmath,amssymb,bm}
\usepackage{graphicx}
\usepackage{floatrow}
\usepackage{placeins}
\usepackage{lastpage}
\usepackage{array}
\usepackage{booktabs}
\usepackage{longtable}
\usepackage{titlesec}
\usepackage[table]{xcolor}
\usepackage[left=2cm,right=2cm,top=3.4cm,bottom=2.5cm]{geometry}
\usepackage{fancyhdr}
\usepackage[hidelinks]{hyperref}
\usepackage{enumitem}
\usepackage{siunitx}
\sisetup{detect-all, per-mode=symbol, group-separator={,}}

%------------------------------------------------------------------ formatting
\titleformat{\section}{\normalfont\large\bfseries}{}{0pt}{\titlerule\newline\llap{}}[{\titlerule[0.4pt]}]
\titleformat{\subsection}{\normalfont\normalsize\bfseries}{}{0pt}{}
\setlength{\headheight}{80pt}
\setlength{\parskip}{4pt}
\setlength{\parindent}{0pt}
\pagestyle{fancy}\fancyhf{}
\renewcommand{\headrulewidth}{0pt}

%------------------------------------------------------- header meta-information
\def\proyecto{Tripteron -- 3-PRRR machining table}
\def\calculo{ }
\def\nombre{Group 2}
\def\revisor{Juan Andr\'es Gallego S\'anchez}
\def\fecha{25 / 05 / 2024}

\fancyhead[L]{\small\begin{tabular}{| l l | l l |}
\hline
\textbf{Project}    & \proyecto & \textbf{Page}     & \thepage/\pageref{LastPage} \\
\textbf{Calculation}& \calculo  & \textbf{Date}     & \fecha \\
\textbf{Analyst}    & \nombre   & \textbf{Reviewer} & \revisor \\
\hline
\end{tabular}}

% one command to open a new calculation sheet: #1 title, #2 analyst
\newcommand{\sheet}[2]{\clearpage\def\calculo{#1}\def\nombre{#2}}

\begin{document}

%==============================================================================
%  COVER
%==============================================================================
\thispagestyle{empty}
\begin{center}
\vspace*{1.2cm}
{\Large\scshape Universidad EAFIT}\\[2pt]
{\large School of Applied Sciences and Engineering}\\[2pt]
{\large Mechanical Engineering -- Machine Design I}\\[1.6cm]

\rule{\textwidth}{1.2pt}\\[10pt]
{\huge\bfseries TRIPTERON}\\[8pt]
{\LARGE Three-degree-of-freedom 3-PRRR parallel machining table}\\[10pt]
{\Large\bfseries Delivery 3 -- Calculation Report}\\[6pt]
{\large Corrected and fully recomputed edition}\\[8pt]
\rule{\textwidth}{1.2pt}\\[1.8cm]

\begin{tabular}{c}
{\large\bfseries Group 2}\\[8pt]
{\large David Amell Osorio}\\[3pt]
{\large Ronny Antonio Bueno}\\[3pt]
{\large Juan Jos\'e Garc\'ia}\\[3pt]
{\large Germ\'an Gabriel Ria\~no Barrera}\\[3pt]
{\large Sebasti\'an Rinc\'on Mart\'inez}\\[3pt]
{\large Juan Manuel Rodr\'iguez Duque}\\[3pt]
{\large David Zuluaga Henao}\\[1.0cm]
{\large\bfseries Reviewer}\\[6pt]
{\large Juan Andr\'es Gallego S\'anchez}\\[1.2cm]
\end{tabular}

\vfill
{\large Medell\'in, Colombia -- 25 May 2024}
\end{center}

%==============================================================================
\clearpage
\setcounter{page}{1}
\def\calculo{Contents and scope}
\def\nombre{Group 2}

\section{Scope of this document}\label{sec:scope}

This report contains the complete engineering verification of the \textbf{Tripteron}, a
three-degree-of-freedom translational parallel machine built with three identical
PRRR legs. The machine carries a milling spindle over a \SI{200}{\milli\metre} cubic
workspace and is driven by three orthogonal lead-screw axes running on linear guides.

Every number presented here was \textbf{recomputed from first principles} with a
purpose-written Python package (\texttt{04\_Calculations/}). No result was copied from
the previous version of the calculation memo: each quantity is produced by executable
code, cross-checked by at least two independent methods, and reported together with the
numerical residual of the check. Appendix A lists, one by one, the
errors found in the earlier memo and the value that replaces each of them --- including
the one that mattered most: the sheet that should have verified the linear guides verified
the lead screw a second time instead, so the most heavily loaded component of the machine
had never been checked.

\subsection{Calculation sheets}

\begin{center}
\small
\begin{tabular}{@{}cl>{\raggedright\arraybackslash}p{5.7cm}l@{}}
\toprule
\textbf{Sheet} & \textbf{Title} & \textbf{Purpose} & \textbf{Analyst} \\
\midrule
1 & Kinematic analysis & Loop-closure model; position, velocity and acceleration of the three legs; workspace. & D. Amell / D. Zuluaga \\
2 & Static analysis    & Actuator forces and internal link loads under the cutting force and self weight. & J. M. Rodr\'iguez / S. Rinc\'on \\
3 & Lead-screw drive   & Driving torque, efficiency, self-locking, screw stresses and column buckling. & J. J. Garc\'ia / D. Zuluaga / G. Ria\~no \\
4 & R-pair guides      & Bushing loads, rod stress and deflection of the three carriages. & R. Bueno / G. Ria\~no / D. Zuluaga \\
5 & Chassis FEA        & Finite-element verification of the welded frame: stress, deflection and buckling. & D. Zuluaga \\
\bottomrule
\end{tabular}
\end{center}

The authorship of every sheet is the one of the original submission, so that this
corrected edition can be read side by side with it. The five sections of the original memo
are all here and none was dropped:

\begin{center}\small
\begin{tabular}{@{}ll l@{}}
\toprule
\textbf{Original memo} & \textbf{Pages} & \textbf{This edition} \\
\midrule
1. C\'alculos est\'aticos        & 3--7   & Sheet 2 \\
2. C\'alculos cinem\'aticos      & 8--22  & Sheet 1 \\
3. C\'alculos tornillo de potencia & 23--29 & Sheet 3 \\
4. C\'alculos gu\'ia par R       & 30--37 & Sheet 3 (its screw content) + Sheet 4 (the guides it never checked) \\
5. C\'alculos chasis, MEF        & 38--60 & Sheet 5, with its original plots \\
\bottomrule
\end{tabular}
\end{center}

Kinematics is placed first because the static analysis needs the poses it produces; in the
original memo the two appear in the opposite order.

\subsection{Reference frame and nomenclature}

The global frame $\{O,x,y,z\}$ is attached to the chassis. $x$ and $y$ are the two
horizontal machining axes and $z$ is vertical, positive upwards. The end effector
position is $\bm{P}=[P_x,P_y,P_z]^{\mathsf T}$ and is measured from the centre of the
workspace; the home pose is $\bm P = \bm 0$.

\begin{center}
\begin{tabular}{@{}ll>{\raggedright\arraybackslash}p{7.2cm}@{}}
\toprule
\textbf{Symbol} & \textbf{Unit} & \textbf{Meaning} \\
\midrule
$b_i$                  & \si{\milli\metre}        & Prismatic (lead-screw) coordinate of leg $i$ \\
$\theta_{Ci},\theta_{Di}$ & \si{\degree}          & Revolute coordinates of the proximal and distal link of leg $i$ \\
$\ell_C=\ell_D$        & \si{\milli\metre}        & Link lengths, \SI{240}{\milli\metre} each \\
$\bm A_i$              & \si{\milli\metre}        & Base point of leg $i$ on the chassis \\
$\bm E_i$              & \si{\milli\metre}        & Attachment point of leg $i$ on the end effector \\
$\bm u_i$              & --                       & Unit vector of the prismatic axis of leg $i$ \\
$\bm q$                & --                       & Generalised coordinate vector, 12 components \\
$\bm\Phi(\bm q,t)$     & --                       & Constraint vector, 12 equations \\
$\bm J=\partial\bm\Phi/\partial\bm q$ & --         & Constraint Jacobian \\
$\bm F_c$              & \si{\newton}             & Cutting force at the tool tip \\
$F_i$                  & \si{\newton}             & Axial force on actuator $i$ \\
\bottomrule
\end{tabular}
\end{center}

\subsection{Machine data used throughout the report}

\begin{center}\small
\begin{tabular}{@{}>{\raggedright\arraybackslash}p{5.1cm}>{\raggedright\arraybackslash}p{5.6cm}>{\raggedright\arraybackslash}p{5.4cm}@{}}
\toprule
\textbf{Item} & \textbf{Value} & \textbf{Source} \\
\midrule
Link lengths $\ell_C,\ell_D$      & \SI{240}{\milli\metre}          & Delivery 2 drawings \\
Stroke of each axis               & \SI{200}{\milli\metre}          & Delivery 1 specification \\
Home prismatic coordinate         & \SI{100}{\milli\metre}          & Mid-stroke \\
Home link angles                  & $+\SI{60}{\degree}$, $-\SI{60}{\degree}$ & Assembly drawing \\
Cutting force $\bm F_c$           & $[80,\,80,\,-120]^{\mathsf T}$ \si{\newton} & Delivery 1, end-mill in aluminium \\
Moving mass (effector + tool)     & \SI{0.574}{\kilo\gram}          & CAD mass properties \\
Arm mass (each link)              & \SI{0.322}{\kilo\gram}          & CAD mass properties \\
Carriage assembly mass            & \SI{15.49}{\kilo\gram}          & CAD mass properties \\
Arm section                       & $25\times25\times\SI{2}{\milli\metre}$ square tube, AISI 1020 & Delivery 2 \\
Lead screw                        & $\varnothing$8\,mm, $p=\SI{2}{\milli\metre}$, 4 starts, trapezoidal & Delivery 2 \\
Chassis material                  & Alloy steel, $S_y=\SI{620}{\mega\pascal}$ & SolidWorks library \\
Motor                             & NEMA 34 86HB250 closed loop, \SI{4.5}{\newton\metre} & Delivery 1 \\
\bottomrule
\end{tabular}
\end{center}

%==============================================================================
\sheet{Sheet 1 -- Kinematic analysis}{D. Amell / D. Zuluaga}
%==============================================================================
\section{Description}\label{sec:kin-desc}

The Tripteron is a 3-PRRR parallel manipulator. Three identical legs connect the fixed
chassis to a single moving platform. Each leg is formed by
\emph{one prismatic joint} driven by a lead screw, followed by \emph{three revolute
joints} whose axes are mutually parallel and perpendicular to the prismatic axis. The
three prismatic axes are mutually orthogonal and aligned with $x$, $y$ and $z$.

This particular arrangement is what makes the Tripteron interesting: the mechanism is a
\emph{fully decoupled} translational parallel machine. Actuator $i$ moves the platform
along axis $i$ only, so the input--output map is the identity and no coordinate
transformation is needed in the controller. The kinematic model developed below proves
this property rather than assuming it.

\section{Objective of the calculation}\label{sec:kin-obj}

\begin{enumerate}[leftmargin=*,nosep]
  \item Build the loop-closure constraint equations of the complete mechanism and solve
        the position problem for an arbitrary trajectory of the tool.
  \item Obtain the velocity and acceleration of every joint by differentiating the
        constraints, and verify them against finite differences of the position solution.
  \item Verify the decoupling property and that the required stroke of each screw stays
        inside the \SI{200}{\milli\metre} travel.
  \item Determine the usable workspace of the machine.
\end{enumerate}

\section{Variables of the calculation model}\label{sec:kin-var}

The generalised coordinate vector contains twelve unknowns:
\begin{equation}
\bm q=\bigl[\,b_1,\;b_2,\;b_3,\;\theta_{C1},\theta_{D1},\;\theta_{C2},\theta_{D2},\;
\theta_{C3},\theta_{D3},\;P_x,P_y,P_z\,\bigr]^{\mathsf T}
\end{equation}

For every leg $i$ the following geometric data are fixed: the base point $\bm A_i$, the
unit vector $\bm u_i$ of the prismatic axis, the two in-plane unit vectors
$(\bm e_{1i},\bm e_{2i})$ of the plane in which the two links rotate, and the platform
attachment point $\bm E_i$ expressed in the platform frame. Since the platform of a
Tripteron does not rotate, $\bm E_i$ is also its offset in the global frame.

\begin{center}
\begin{tabular}{@{}cccc@{}}
\toprule
\textbf{Leg} & $\bm A_i$ [mm] & $\bm u_i$ & $\bm E_i$ [mm] \\
\midrule
1 & $[-162.5,\,-240,\,-62.5]$ & $[1,0,0]$ & $[62.5,\,0,\,62.5]$ \\
2 & $[-302.5,\,-100,\,0]$     & $[0,1,0]$ & $[62.5,\,0,\,0]$ \\
3 & $[-240,\,0,\,-162.5]$     & $[0,0,1]$ & $[0,\,0,\,62.5]$ \\
\bottomrule
\end{tabular}
\end{center}

\section{Calculation model}\label{sec:kin-model}

\subsection{Position: loop-closure constraints}

Each leg contributes one vector loop that must close on the platform attachment point,
plus one planarity condition. Writing $\bm p_i$ for the carriage position and
$\bm k_i$ for the elbow position,
\begin{align}
\bm p_i &= \bm A_i + b_i\,\bm u_i \\
\bm k_i &= \bm p_i + \ell_C\bigl(\cos\theta_{Ci}\,\bm e_{1i} + \sin\theta_{Ci}\,\bm e_{2i}\bigr) \\
\bm\Phi_i &= \bm k_i + \ell_D\bigl(\cos\theta_{Di}\,\bm e_{1i} + \sin\theta_{Di}\,\bm e_{2i}\bigr)
              - \bigl(\bm P + \bm E_i\bigr) \;=\; \bm 0
\label{eq:loop}
\end{align}
Equation~\eqref{eq:loop} gives three scalar equations per leg, nine in total. The
remaining three equations are the driving constraints that impose the prescribed tool
path $\bm P^{\ast}(t)$:
\begin{equation}
\bm\Phi_d = \bm P - \bm P^{\ast}(t) = \bm 0
\end{equation}
so the complete constraint vector $\bm\Phi(\bm q,t)\in\mathbb{R}^{12}$ matches the twelve
unknowns and the mechanism has zero degrees of freedom once the path is imposed --- the
correct formulation for a kinematic (not dynamic) analysis.

The nonlinear system is solved with Newton--Raphson,
\begin{equation}
\bm q^{(k+1)} = \bm q^{(k)} - \bm J^{-1}\bigl(\bm q^{(k)}\bigr)\,\bm\Phi\bigl(\bm q^{(k)},t\bigr),
\qquad
\bm J = \frac{\partial\bm\Phi}{\partial\bm q}
\end{equation}
using the previous time step as the initial guess, which keeps the solution on a single
assembly branch (elbow-up) throughout the trajectory.

\subsection{Velocity and acceleration}

Differentiating the constraints once and twice with respect to time,
\begin{align}
\bm J\,\dot{\bm q} &= -\,\bm\Phi_t \\
\bm J\,\ddot{\bm q} &= -\,\dot{\bm J}\,\dot{\bm q} - 2\,\bm\Phi_{qt}\dot{\bm q} - \bm\Phi_{tt}
\end{align}
Because the only explicit time dependence sits in the driving constraints,
$\bm\Phi_t=-\dot{\bm P}^{\ast}$ and $\bm\Phi_{tt}=-\ddot{\bm P}^{\ast}$, and
$\bm\Phi_{qt}=\bm 0$. Both systems are linear in the unknown derivatives and share the
same Jacobian, which is factorised once per time step.

\subsection{Independent verification: closed-form inverse kinematics}

For each leg the two revolute coordinates can be obtained analytically, because once the
prismatic coordinate is known the leg reduces to a planar 2R chain. With
$\bm d = \bm P+\bm E_i-\bm p_i$, $u=\bm d\cdot\bm e_{1i}$, $v=\bm d\cdot\bm e_{2i}$ and
$r^2=u^2+v^2$,
\begin{equation}
\cos\beta=\frac{r^2-\ell_C^2-\ell_D^2}{2\,\ell_C\ell_D},\qquad
\gamma=\operatorname{atan2}\!\bigl(\ell_D\sin\beta,\;\ell_C+\ell_D\cos\beta\bigr),
\end{equation}
\begin{equation}
\theta_{Ci}=\operatorname{atan2}(v,u)-\gamma,\qquad \theta_{Di}=\theta_{Ci}+\beta .
\end{equation}
The elbow-up branch is selected with $\beta<0$. This closed form is used only as a check
of the Newton--Raphson solution, never as the solution itself.

\section{Values of the calculation model}\label{sec:kin-val}

Three trajectories representative of the machine duty cycle were analysed:

\begin{center}
\begin{tabular}{@{}cl>{\raggedright\arraybackslash}p{7.6cm}@{}}
\toprule
\textbf{Case} & \textbf{Name} & \textbf{Definition} \\
\midrule
1 & Straight cut      & \SI{120}{\milli\metre} along $x$ at a constant feed of \SI{10}{\milli\metre\per\second}. \\
2 & Accelerated move  & Rapid traverse along $y$, trapezoidal profile, $a=\SI{20}{\milli\metre\per\second\squared}$, $t=\SI{4}{\second}$. \\
3 & Helical pocket    & Circle of radius \SI{60}{\milli\metre} in $xy$ at \SI{10}{\milli\metre\per\second} with a simultaneous plunge of \SI{1}{\milli\metre\per\second}. \\
\bottomrule
\end{tabular}
\end{center}

\section{Results and conclusions}\label{sec:kin-res}

\subsection{Numerical quality of the solution}

\begin{center}
\begin{tabular}{@{}lccc@{}}
\toprule
\textbf{Quantity} & \textbf{Case 1} & \textbf{Case 2} & \textbf{Case 3} \\
\midrule
Newton iterations (max.)                        & 3 & 3 & 4 \\
Constraint residual $\lVert\bm\Phi\rVert$ [mm]  & $1.4\times10^{-11}$ & $7.7\times10^{-11}$ & $1.3\times10^{-13}$ \\
Deviation from closed form [mm]                 & $2.6\times10^{-14}$ & $2.1\times10^{-13}$ & $1.4\times10^{-14}$ \\
Velocity vs.\ finite differences [mm/s]         & $8.2\times10^{-9}$ & $0.10^{\dagger}$ & $4.1\times10^{-4}$ \\
Acceleration vs.\ finite differences [mm/s$^2$] & $1.1\times10^{-9}$ & $20^{\dagger}$ & $6.9\times10^{-5}$ \\
\bottomrule
\end{tabular}
\end{center}
{\footnotesize $^{\dagger}$ Case 2 uses a trapezoidal profile whose acceleration is
discontinuous at the two switching instants. The finite-difference estimate is
meaningless exactly at those two samples; away from them the agreement is of the same
order as in the other two cases. The discrepancy therefore confirms the profile, it does
not indicate an error in the model.}

The residual of the constraint equations never exceeds \SI{8e-11}{\milli\metre} and the
analytical solution agrees with Newton--Raphson to $10^{-13}$\,mm, i.e.\ to machine
precision. The kinematic model is therefore verified.

\subsection{Decoupling}

For every pose of the three trajectories, the block of the Jacobian that relates the
actuator coordinates to the platform coordinates is the identity matrix:
\begin{equation}
\dot b_1=\dot P_x,\qquad \dot b_2=\dot P_y,\qquad \dot b_3=\dot P_z .
\end{equation}
The decoupling property of the Tripteron is confirmed numerically. Each screw therefore
sees exactly the commanded feed of its own axis, which is the reason a simple
three-axis controller with no coordinate transformation is sufficient.

\subsection{Stroke usage}

\begin{center}
\begin{tabular}{@{}lccc@{}}
\toprule
\textbf{Case} & $b_1$ [mm] & $b_2$ [mm] & $b_3$ [mm] \\
\midrule
1 -- straight cut     & 40.0 -- 160.0 & 100.0 & 100.0 \\
2 -- accelerated move & 100.0 & 60.0 -- 140.0 & 100.0 \\
3 -- helical pocket   & 40.0 -- 160.0 & 40.0 -- 160.0 & 62.3 -- 100.0 \\
\bottomrule
\end{tabular}
\end{center}

All three cases stay inside the \SIrange{0}{200}{\milli\metre} travel with at least
\SI{40}{\milli\metre} of margin at each end, so no trajectory reaches a hard stop.
The maximum joint speeds are \SI{40}{\milli\metre\per\second} (case 2) and the maximum
joint accelerations \SI{20}{\milli\metre\per\second\squared}, both well inside the
capability of the selected motor-screw combination.

\begin{figure}[htbp]\centering
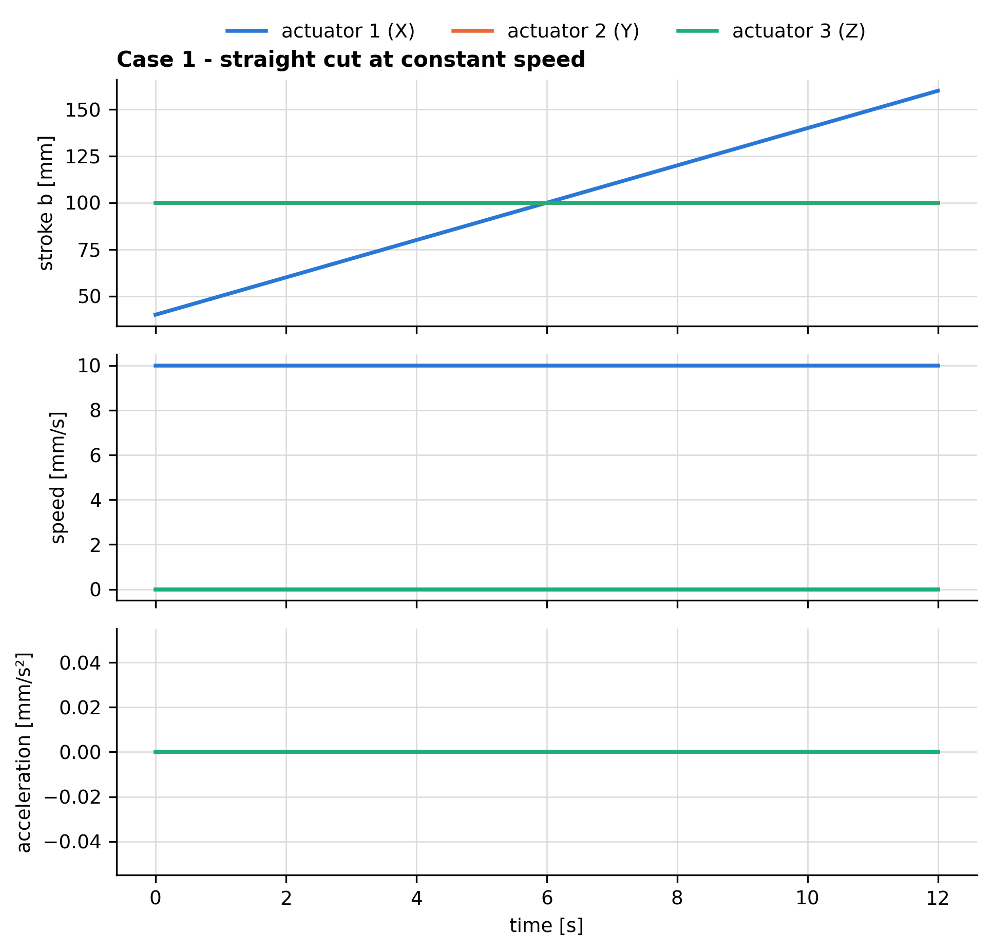
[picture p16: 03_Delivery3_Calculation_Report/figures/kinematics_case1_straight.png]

\caption{Case 1 -- straight cut: joint coordinates, speeds and accelerations.}
\end{figure}

\begin{figure}[htbp]\centering
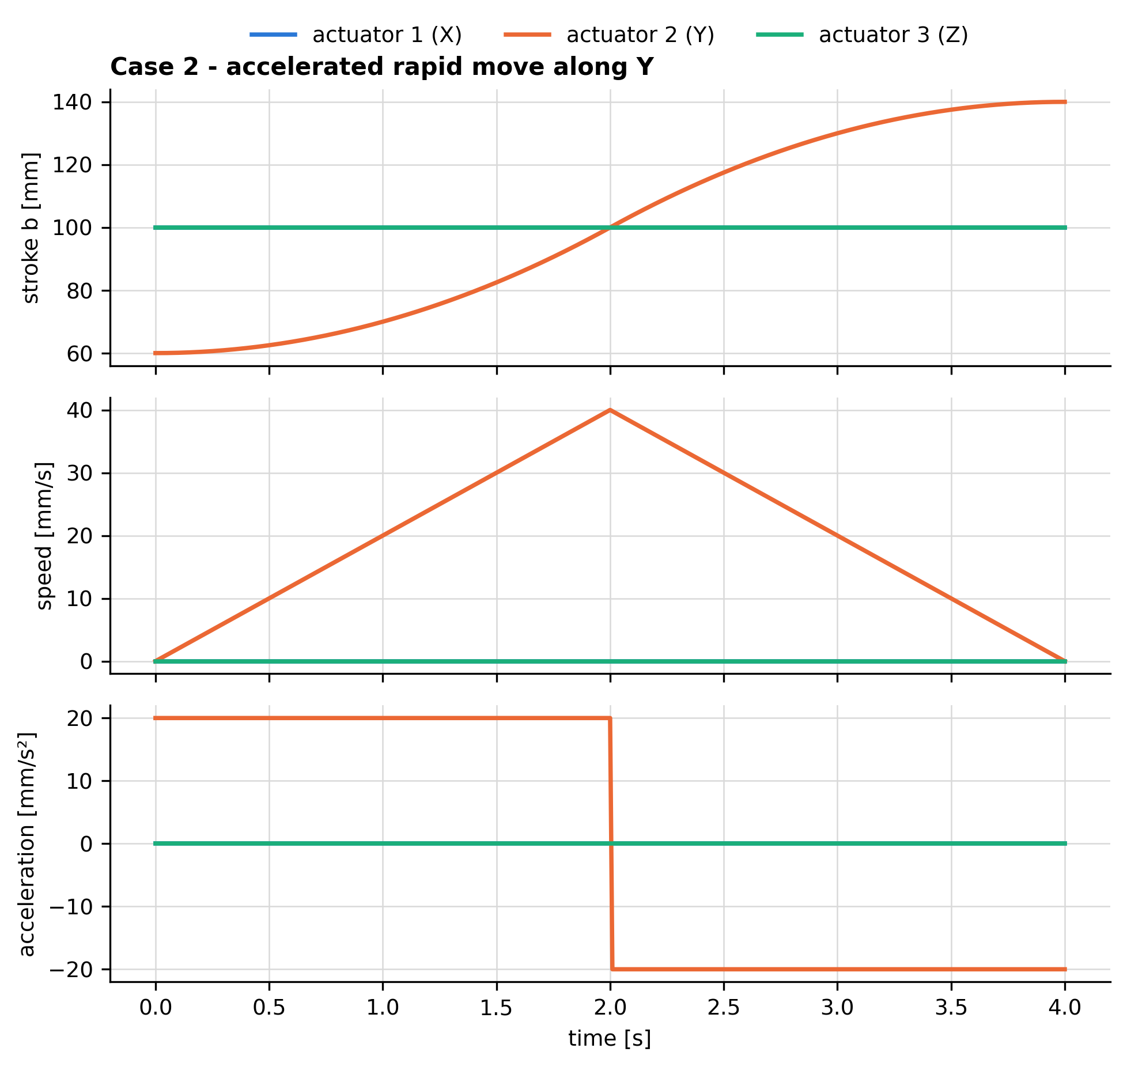
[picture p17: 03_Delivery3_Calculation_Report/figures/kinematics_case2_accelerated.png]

\caption{Case 2 -- accelerated rapid traverse along $y$.}
\end{figure}

\begin{figure}[htbp]\centering
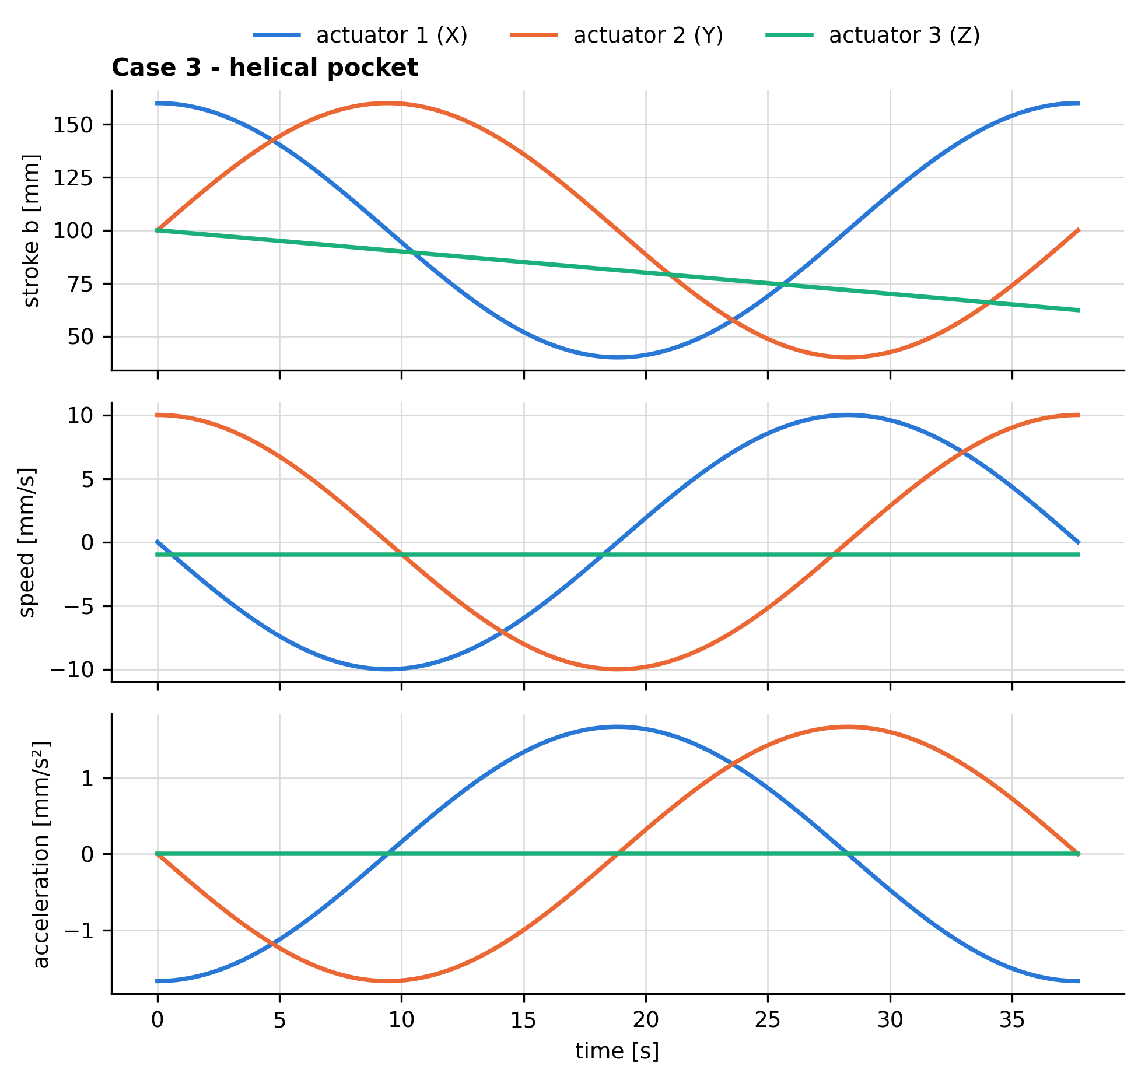
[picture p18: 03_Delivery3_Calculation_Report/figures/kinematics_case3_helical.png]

\caption{Case 3 -- helical pocketing move.}
\end{figure}

\FloatBarrier
\subsection{Workspace}

The reachable workspace was mapped by solving the inverse kinematics on a
\SI{5}{\milli\metre} grid and rejecting the poses for which any leg leaves its stroke or
any 2R chain becomes unreachable ($r>\ell_C+\ell_D$ or $r<|\ell_C-\ell_D|$). Out of
\num{68921} sampled points, the full \SI{200}{\milli\metre} cube is reachable:

\begin{center}
\begin{tabular}{@{}lc@{}}
\toprule
\textbf{Quantity} & \textbf{Value} \\
\midrule
Bounds in $x$, $y$, $z$ & $\pm\SI{100}{\milli\metre}$ each \\
Usable volume           & \SI{8.615}{\deci\metre\cubed} \\
Shape                   & Cube, no interior singularity \\
\bottomrule
\end{tabular}
\end{center}

The workspace is a perfect cube --- a direct consequence of the decoupling --- and no
singular pose was found inside it, since $\det\bm J$ keeps a constant sign over the whole
grid. This is the main practical advantage of the Tripteron over a delta or a Stewart
platform of comparable size.

\begin{figure}[htbp]\centering
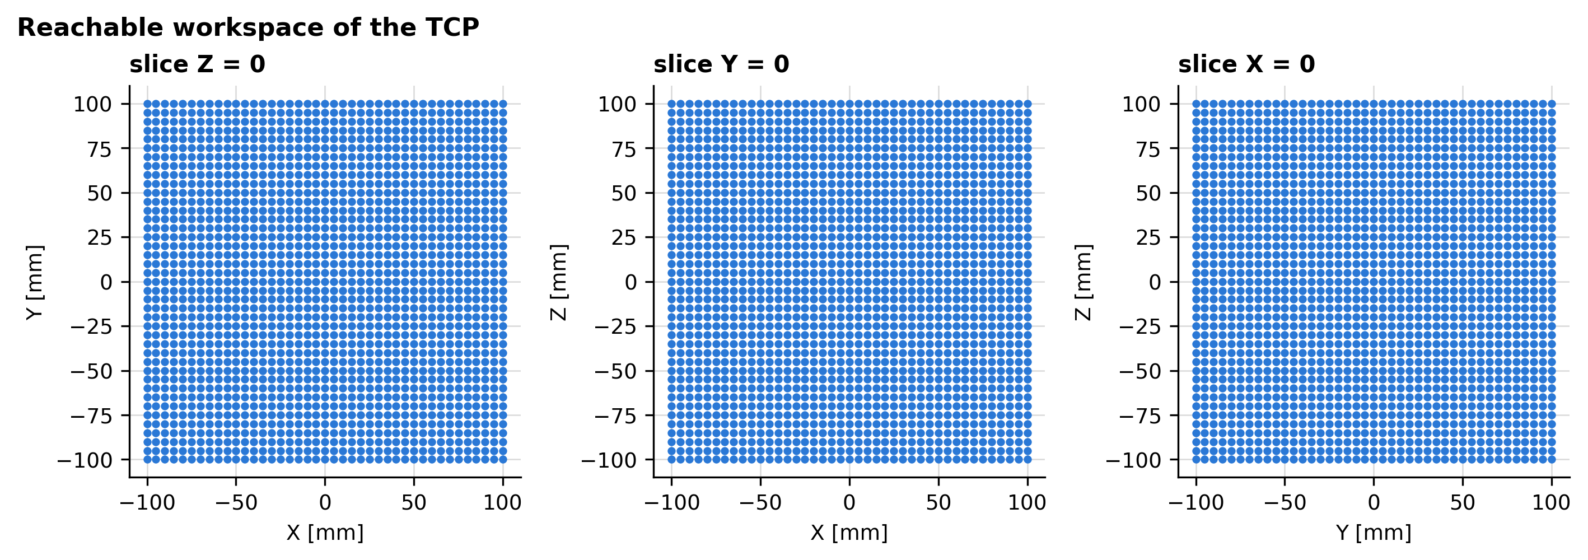
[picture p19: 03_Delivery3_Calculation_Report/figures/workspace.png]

\caption{Reachable workspace of the machine: the full \SI{200}{\milli\metre} cube.}
\end{figure}
\FloatBarrier

%==============================================================================
\sheet{Sheet 2 -- Static analysis}{J. M. Rodr\'iguez / S. Rinc\'on}
%==============================================================================
\section{Description}\label{sec:sta-desc}

With the geometry of every pose known from Sheet~1, the second calculation determines the
forces that the machine has to carry: the axial force each lead screw must produce, the
reactions at the twelve joints, and the internal bending moment of the six arms. The load
case is the cutting force at the tool tip plus the self weight of all moving bodies.

The Tripteron is an \emph{over-constrained} parallel mechanism: three closed loops share a
single platform. The rigid-body equilibrium system is therefore statically indeterminate,
and this is treated explicitly below instead of being ignored.

\section{Objective of the calculation}\label{sec:sta-obj}

\begin{enumerate}[leftmargin=*,nosep]
  \item Obtain the axial force on each actuator for the worst pose inside the workspace.
  \item Obtain the joint reactions and the maximum bending stress in the arms.
  \item Define the design axial load that Sheet~3 uses to size the lead screw.
  \item Cross-check the result with an independent energy method.
\end{enumerate}

\section{Variables of the calculation model}\label{sec:sta-var}

Each of the ten moving bodies (three carriages, six links and the platform) contributes
six equilibrium equations, and each joint contributes its unknown reaction components:
six per prismatic joint (two transverse forces, three moments and the actuator force) and
five per revolute joint (three forces and the two moments perpendicular to its axis), i.e.\
21 per leg. Assembling the whole machine gives
\begin{center}
\begin{tabular}{@{}lc@{}}
\toprule
Equilibrium equations & 60 \\
Unknown reaction components & 63 \\
Rank of the system matrix & 60 \\
Redundant (statically indeterminate) components & 3 \\
\bottomrule
\end{tabular}
\end{center}

The three redundant components are the price of the closed kinematic chains: the
platform is held by three legs where two would already fix its three translations. A
rigid-body model cannot distribute those three components; only an elastic model can.

This number is not arbitrary. The mobility count of Delivery~1 gives, for 10 moving
bodies and 12 one-degree-of-freedom joints,
$M=6\times10-12\times5=0$, while the machine evidently has three degrees of freedom.
The difference of three is precisely the number of redundant constraints introduced by
the special geometry of the Tripteron, and it reappears here as the three redundant
reaction components. The kinematic and the static models therefore agree on the degree of
over-constraint of the machine.

\section{Calculation model}\label{sec:sta-model}

\subsection{Rigid-body equilibrium}

For every body $k$ with weight $\bm W_k$ acting at its centre of mass $\bm c_k$,
\begin{equation}
\sum_j \bm R_{kj} + \bm W_k + \bm F_{\text{ext},k} = \bm 0,
\qquad
\sum_j (\bm r_{kj}-\bm c_k)\times\bm R_{kj} + \bm M_{\text{ext},k} = \bm 0
\end{equation}
where $\bm R_{kj}$ is the reaction transmitted to body $k$ at joint $j$ and
$\bm r_{kj}$ is the position of that joint. Each revolute joint transmits three force
components and the two moment components perpendicular to its axis; each prismatic joint
transmits the two force components perpendicular to its axis, the three moment components,
and the actuator force along the axis.

Collecting the unknowns in $\bm x\in\mathbb R^{63}$ gives the linear system
$\bm A\,\bm x=\bm y$ with $\bm A\in\mathbb R^{60\times63}$. Since
$\operatorname{rank}(\bm A)=60$ the system is consistent but has a three-parameter family
of solutions. The \emph{minimum-norm} solution is selected,
\begin{equation}
\bm x^{\ast}=\arg\min\lVert\bm x\rVert_2 \quad\text{subject to}\quad \bm A\bm x=\bm y,
\end{equation}
computed with a least-squares (SVD) solver. This is the physically meaningful choice for a
symmetric, equally stiff structure, and it is conservative for the arms because it does
not concentrate the redundant load in a single leg.

\subsection{Independent verification: virtual work}

The actuator forces do not depend on the redundant components, so they can be obtained
exactly from the principle of virtual work without solving the indeterminate system:
\begin{equation}
F_i = -\Bigl(\bm F_c\cdot\frac{\partial\bm P}{\partial b_i}
      + \sum_k \bm W_k\cdot\frac{\partial\bm c_k}{\partial b_i}\Bigr)
\label{eq:vw}
\end{equation}
The derivatives $\partial\bm c_k/\partial b_i$ are evaluated by central finite differences
of the position solution of Sheet~1, with a perturbation of \SI{1e-4}{\milli\metre}. This
route shares nothing with the equilibrium assembly except the geometry, so agreement
between the two is a genuine check.

\subsection{Arm stresses}

The arms are $25\times25\times\SI{2}{\milli\metre}$ square tubes:
\begin{equation}
A=\SI{184}{\milli\metre\squared},\qquad
I=\SI{16345}{\milli\metre\tothe{4}},\qquad
c=\SI{12.5}{\milli\metre},\qquad
W=\frac{I}{c}=\SI{1307.6}{\milli\metre\cubed}
\end{equation}
and the bending stress follows from the internal moment at the built-in end,
$\sigma_b=M/W$.

\section{Values of the calculation model}\label{sec:sta-val}

The cutting force is $\bm F_c=[80,\,80,\,-120]^{\mathsf T}$\,\si{\newton}: two horizontal
components from the end-mill and a vertical component pointing \emph{downwards}, i.e.\
pressing the tool into the part. Four poses were evaluated: the home pose and the three
corners of the workspace that maximise, respectively, the vertical, the diagonal and the
mixed load.

\section{Results and conclusions}\label{sec:sta-res}

\subsection{Actuator forces}

\begin{center}
\begin{tabular}{@{}lccccc@{}}
\toprule
\textbf{Pose} & $F_x$ [N] & $F_y$ [N] & $F_z$ [N] & \textbf{Worst arm} & $\sigma_b$ [MPa] \\
\midrule
Home $(0,0,0)$          & $-80.9$ & $-80.9$ & $+157.9$ & link C3 & 25.4 \\
Corner $(+90,+90,+90)$  & $-81.4$ & $-81.4$ & $+156.3$ & link C3 & 25.1 \\
Corner $(-90,-90,-90)$  & $-79.4$ & $-79.4$ & $\bm{+162.0}$ & link C3 & \textbf{26.1} \\
Corner $(+90,-90,+90)$  & $-81.4$ & $-79.4$ & $+155.0$ & link C3 & 24.9 \\
\bottomrule
\end{tabular}
\end{center}

The equilibrium residual $\lVert\bm A\bm x-\bm y\rVert$ is below
\SI{2.7e-9}{\newton} in every pose, and the actuator forces obtained from
equation~\eqref{eq:vw} agree with the equilibrium solution to better than
\SI{1e-6}{\newton}. Two completely independent methods therefore give the same answer.

\textbf{Design axial load:} $\bm{F_{\max}}=\SI{162.0}{\newton}$, at the corner
$(-90,-90,-90)$, on the vertical axis. This value is carried forward to Sheet~3.

\subsection{Interpretation}

\begin{itemize}[leftmargin=*,nosep]
  \item The horizontal actuators carry almost exactly the horizontal cutting force
        ($\approx\SI{81}{\newton}$ against \SI{80}{\newton} applied); the extra
        \SI{0.9}{\newton} is the weight of the arms projected on the horizontal axes. This
        is the expected behaviour of a decoupled machine and is a further confirmation of
        the kinematic model.
  \item The vertical actuator carries the vertical cutting force \emph{plus} the entire
        weight of the moving assembly: with the spindle off, gravity alone demands
        \SI{37.9}{\newton} on axis $z$ against \SI{0.9}{\newton} on each horizontal axis.
        The vertical screw is therefore the critical one and must never be back-driven.
  \item The variation of the actuator force across the whole workspace is only
        \SI{4.5}{\percent} ($155.0$ to \SI{162.0}{\newton}), so a single worst-case load is
        a sound basis for sizing the transmission.
  \item The maximum bending stress in the arms is \SI{26.1}{\mega\pascal} against a yield
        strength of \SI{250}{\mega\pascal} for AISI 1020, i.e.\ a safety factor of
        \textbf{9.6}. The arms are not the limiting component; they were sized by stiffness
        and by the need to accommodate the bearing bores, not by strength.
\end{itemize}

\begin{figure}[htbp]\centering

\caption{Actuator forces and worst arm bending stress for the four poses analysed.}
\end{figure}
\FloatBarrier

%==============================================================================
\sheet{Sheet 3 -- Lead-screw drive}{J. J. Garc\'ia / D. Zuluaga / G. Ria\~no}
%==============================================================================
\section{Description}\label{sec:scr-desc}

Each axis is driven by a trapezoidal lead screw turned directly by a stepper motor. The
nut is fixed to the carriage, which runs on two linear guides (the R-pair guide rails of
Delivery 2) that take all the transverse load, so the screw is loaded axially and in
torsion only. This sheet sizes that screw for the design load obtained in Sheet~2.

\section{Objective of the calculation}\label{sec:scr-obj}

\begin{enumerate}[leftmargin=*,nosep]
  \item Compute the torque required to raise and to lower the load, including collar friction.
  \item Compute the mechanical efficiency and check whether the screw is self-locking.
  \item Verify the screw body against the combined axial, torsional, thread-shear and
        bearing stresses.
  \item Verify the screw as a column in compression.
\end{enumerate}

\section{Variables of the calculation model}\label{sec:scr-var}

\begin{center}
\begin{tabular}{@{}llc@{}}
\toprule
\textbf{Symbol} & \textbf{Description} & \textbf{Value} \\
\midrule
$d$        & Nominal diameter                       & \SI{8}{\milli\metre} \\
$p$        & Thread pitch                           & \SI{2}{\milli\metre} \\
$n_s$      & Number of starts                       & 4 \\
$L$        & Lead, $L=n_s\,p$                       & \SI{8}{\milli\metre} \\
$d_m$      & Mean diameter, $d-p/2$                 & \SI{7}{\milli\metre} \\
$d_r$      & Root diameter, $d-p$                   & \SI{6}{\milli\metre} \\
$\alpha$   & Half thread angle (trapezoidal)        & \SI{15}{\degree} \\
$\lambda$  & Lead angle, $\arctan\!\bigl(L/\pi d_m\bigr)$ & \SI{19.99}{\degree} \\
$\mu$      & Thread friction coefficient (steel--bronze, greased) & 0.15 \\
$\mu_c$    & Collar friction coefficient (thrust bearing) & 0.02 \\
$d_c$      & Mean collar diameter                   & \SI{6}{\milli\metre} \\
$n_t$      & Engaged threads in the nut             & 6 \\
$\ell$     & Unsupported screw length               & \SI{500}{\milli\metre} \\
$E$        & Young's modulus, steel                 & \SI{207}{\giga\pascal} \\
$S_y$      & Yield strength                         & \SI{370}{\mega\pascal} \\
$F$        & Design axial load (Sheet~2)            & \SI{162.0}{\newton} \\
\bottomrule
\end{tabular}
\end{center}

\section{Calculation model}\label{sec:scr-model}

\subsection{Torque (Shigley, power screws)}

For a trapezoidal thread the friction coefficient is divided by $\cos\alpha$:
\begin{align}
T_R &= \frac{F\,d_m}{2}\left(\frac{L+\pi\mu d_m\sec\alpha}{\pi d_m-\mu L\sec\alpha}\right)
       + \frac{F\,\mu_c\,d_c}{2} \label{eq:TR}\\[4pt]
T_L &= \frac{F\,d_m}{2}\left(\frac{\pi\mu d_m\sec\alpha-L}{\pi d_m+\mu L\sec\alpha}\right)
       + \frac{F\,\mu_c\,d_c}{2} \label{eq:TL}
\end{align}
and the efficiency of the screw pair is
\begin{equation}
e=\frac{F\,L}{2\pi\,T_R}.
\label{eq:eff}
\end{equation}
Equation~\eqref{eq:eff} is bounded above by unity by construction. \emph{Any result above
$1$ means an arithmetic error, not a good screw.}

\subsection{Self-locking}

The screw holds the load without a brake only if the thread friction torque exceeds the
torque produced by the load, i.e.\ if the first term of~\eqref{eq:TL} is positive:
\begin{equation}
\mu \;\ge\; \frac{L\cos\alpha}{\pi d_m}.
\label{eq:selflock}
\end{equation}

\subsection{Stresses in the screw body}

With $A_r=\pi d_r^2/4$ the root area, $n_t$ engaged threads and thread thickness $p/2$ at
the root:
\begin{align}
\sigma_a &= \frac{F}{A_r}
&\tau_t &= \frac{16\,T_R}{\pi d_r^{3}} \\
\tau_{\text{thread}} &= \frac{2F}{\pi d_r\,w\,p\,n_t}
&\sigma_{\text{bearing}} &= \frac{2F}{\pi d_m\,p\,n_t}
\end{align}
where $w=0.38$ is the fraction of the pitch that the thread actually occupies at its root
on a trapezoidal profile. The body of the screw is then checked with the
distortion-energy (von Mises) criterion,
\begin{equation}
\sigma' = \sqrt{\sigma_a^2 + 3\,\tau_t^2} ,
\qquad n = \frac{S_y}{\sigma'} .
\label{eq:vm}
\end{equation}
The thread shear is \emph{not} superposed in equation~\eqref{eq:vm}: it acts on the
cylindrical surface at the root of the thread, not on the cross-section of the body, so it
is a separate check with its own margin,
$n_{\text{thread}} = 0.577\,S_y/\tau_{\text{thread}}$.

\subsection{Column buckling}

The screw is treated as a pinned--pinned column, $K=1$. With
$I=\pi d_r^4/64$, $r_g=\sqrt{I/A_r}=d_r/4$ and slenderness $\ell_e/r_g$, the transition
slenderness between the Johnson and the Euler regimes is
\begin{equation}
\left(\frac{\ell_e}{r_g}\right)_{\!1}=\sqrt{\frac{2\pi^2E}{S_y}} ,
\end{equation}
and the critical load is
\begin{equation}
P_{cr}=\frac{\pi^2EI}{(K\ell)^2}\quad\text{(Euler)},
\qquad
P_{cr}=A_r\left[S_y-\frac{1}{E}\left(\frac{S_y\,\ell_e}{2\pi r_g}\right)^{2}\right]\quad\text{(Johnson)} .
\end{equation}

\section{Values and results}\label{sec:scr-res}

\subsection{Torque and efficiency}

\begin{center}
\begin{tabular}{@{}lcc@{}}
\toprule
\textbf{Quantity} & \textbf{Design load, \SI{162.0}{\newton}} & \textbf{Delivery 1 load, \SI{151.9}{\newton}} \\
\midrule
Thread torque, raising $T_{R,\text{thread}}$ & \SI{311.9}{\newton\milli\metre} & \SI{292.5}{\newton\milli\metre} \\
Collar torque $T_c$                          & \SI{9.7}{\newton\milli\metre}   & \SI{9.1}{\newton\milli\metre} \\
\textbf{Total raising torque} $T_R$          & \textbf{\SI{321.6}{\newton\milli\metre}} & \SI{301.6}{\newton\milli\metre} \\
Total lowering torque $T_L$                  & \SI{-102.2}{\newton\milli\metre} & \SI{-95.8}{\newton\milli\metre} \\
Efficiency $e$                               & \textbf{\SI{64.1}{\percent}} & \SI{64.1}{\percent} \\
$\mu$ required for self-locking              & 0.351 & 0.351 \\
Self-locking with $\mu=0.15$?                & \textbf{No} & No \\
Fraction of motor holding torque used        & \SI{7.1}{\percent} & \SI{6.7}{\percent} \\
\bottomrule
\end{tabular}
\end{center}

\subsection{Stresses and safety factors}

\begin{center}
\begin{tabular}{@{}lcc@{}}
\toprule
\textbf{Quantity} & \textbf{Value} & \textbf{Limit / remark} \\
\midrule
Root area $A_r$                     & \SI{28.27}{\milli\metre\squared} & --- \\
Axial stress $\sigma_a$             & \SI{5.73}{\mega\pascal}  & compression \\
Torsional stress $\tau_t$           & \SI{7.58}{\mega\pascal}  & from $T_R$ \\
Thread shear $\tau_{\text{thread}}$ & \SI{3.77}{\mega\pascal}  & 6 engaged threads, $n_{\text{thread}} = 56.6$ \\
Bearing stress $\sigma_{\text{bearing}}$ & \SI{1.23}{\mega\pascal} & bronze nut, limit $\approx$ \SI{17}{\mega\pascal} \\
von Mises $\sigma'$                 & \SI{14.33}{\mega\pascal} & $S_y=\SI{370}{\mega\pascal}$ \\
\textbf{Static safety factor}       & \textbf{25.8}            & --- \\
\midrule
Second moment $I$                   & \SI{63.6}{\milli\metre\tothe{4}} & $\pi d_r^4/64$ \\
Radius of gyration $r_g$            & \SI{1.5}{\milli\metre}   & $d_r/4$ \\
Slenderness $\ell/r_g$              & 333                       & limit 105 $\Rightarrow$ Euler \\
Critical load $P_{cr}$              & \SI{519.9}{\newton}      & pinned--pinned \\
\textbf{Buckling safety factor}     & \textbf{3.21}            & --- \\
\bottomrule
\end{tabular}
\end{center}

\begin{figure}[htbp]\centering
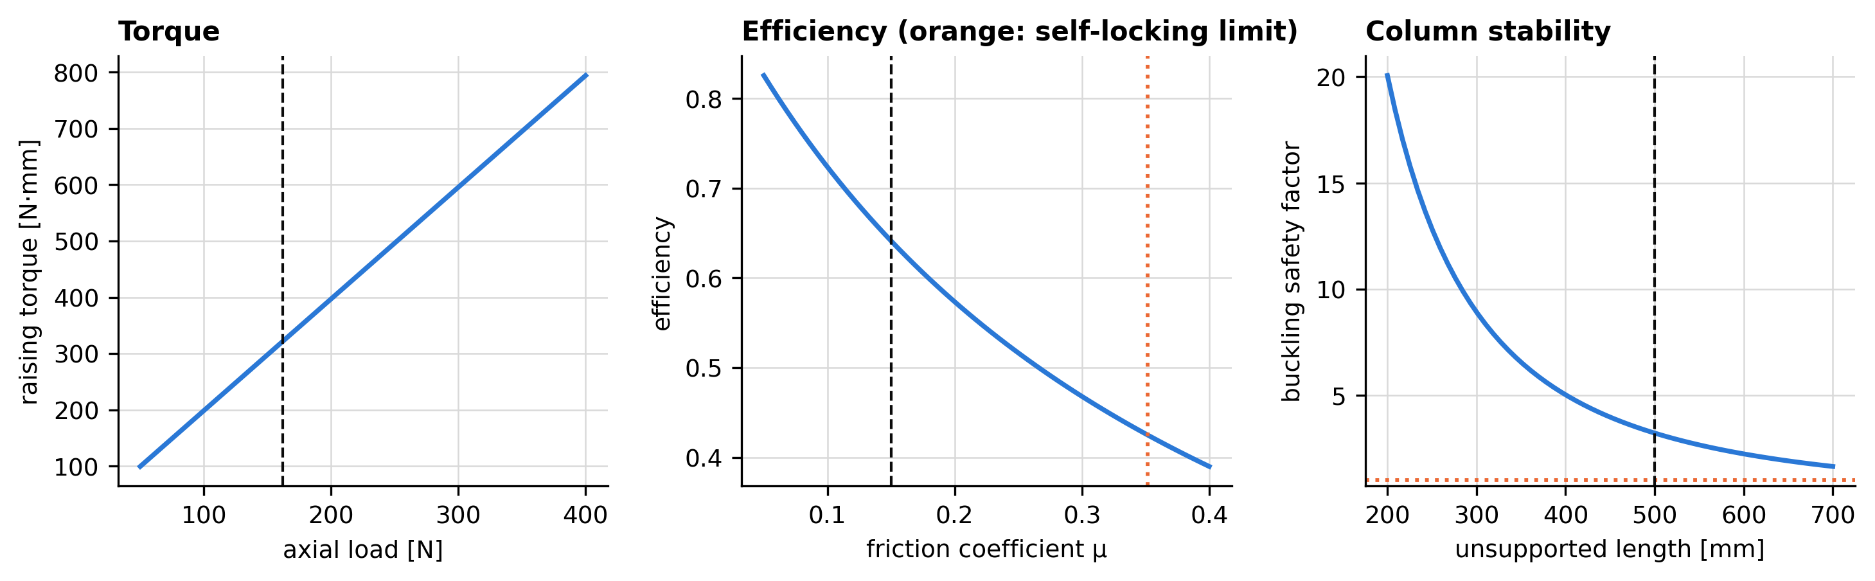
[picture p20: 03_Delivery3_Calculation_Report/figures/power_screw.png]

\caption{Lead-screw verification: torque breakdown, stress components and column check.}
\end{figure}
\FloatBarrier

\subsection{Conclusions}

\begin{enumerate}[leftmargin=*]
  \item \textbf{Strength is not the driver.} The von Mises stress of \SI{14.3}{\mega\pascal}
        gives a safety factor of 25.8. The \SI{8}{\milli\metre} screw is far stronger than
        the load requires; it was selected for availability and for the compatibility of
        its \SI{8}{\milli\metre} lead with the required feed rates.
  \item \textbf{Buckling governs the screw.} With a safety factor of 3.21 against Euler
        buckling, the column check is eight times more restrictive than the stress check.
        This is the correct behaviour for a long, slender screw and it is the criterion
        that must be re-examined if the stroke is ever increased: $P_{cr}$ falls with the
        square of the length, so a \SI{700}{\milli\metre} screw would drop to
        \SI{265}{\newton} and a safety factor of 1.6, which would no longer be acceptable.
  \item \textbf{The screw is not self-locking.} A 4-start thread has a lead angle of
        \SI{19.99}{\degree}; equation~\eqref{eq:selflock} requires $\mu\ge0.351$ while the
        greased steel--bronze pair gives $\mu=0.15$. The vertical axis \emph{will}
        back-drive under gravity if the motor is de-energised. Two consequences, both
        already covered by the selected hardware:
        \begin{itemize}[nosep]
          \item the closed-loop NEMA 34 motor must keep holding current at standstill ---
                it needs only \SI{0.32}{\newton\metre} out of \SI{4.5}{\newton\metre},
                i.e.\ \SI{7.1}{\percent} of its holding torque;
          \item an electromagnetic brake or a mechanical stop is mandatory on the $z$ axis
                for maintenance and for a power failure. This is a safety item, not an
                optional one.
        \end{itemize}
        The efficiency of \SI{64.1}{\percent} is the direct trade-off: a fast, efficient,
        non-self-locking screw.
  \item \textbf{Motor sizing is comfortable.} \SI{0.32}{\newton\metre} required against
        \SI{4.5}{\newton\metre} available leaves a factor of 14 for acceleration,
        preload, friction ageing and the inertia of the screw itself.
\end{enumerate}

%==============================================================================
\sheet{Sheet 4 -- R-pair guides and carriages}{R. Bueno / G. Ria\~no / D. Zuluaga}
%==============================================================================
\section{Description}\label{sec:gui-desc}

Each axis is guided by two parallel hardened rods on which the carriage of the R
pair slides. The nut on the lead screw takes the axial load, which Sheet~3 has already
verified; \emph{everything else} the joint has to carry --- the two transverse force
components and the three moment components --- goes through the rods and their linear
bushings. Because the arms of a Tripteron reach out from the carriage, that moment is
large, and this is the sheet that decides whether the guides can take it.

\section{Objective of the calculation}\label{sec:gui-obj}

\begin{enumerate}[leftmargin=*,nosep]
  \item Obtain the load on the most loaded linear bushing of each carriage and compare it
        with the static rating of the bushing fitted.
  \item Obtain the bending stress and the deflection of the guide rods, and compare the
        deflection with the deflection of the frame.
  \item Identify which geometric parameter of the carriage governs the result.
\end{enumerate}

\section{Variables of the calculation model}\label{sec:gui-var}

\begin{center}
\begin{tabular}{@{}llc@{}}
\toprule
\textbf{Symbol} & \textbf{Description} & \textbf{Value} \\
\midrule
$d$   & Guide rod diameter (12 H7 bore on the bearing support drawing) & \SI{12}{\milli\metre} \\
$\ell$& Clear span of the rod between end supports                     & \SI{500}{\milli\metre} \\
$b$   & Distance between the two bushings of one carriage              & \SI{60}{\milli\metre} \\
$s$   & Track width, distance between the two rods                     & \SI{115}{\milli\metre} \\
$I$   & Second moment of area of a rod, $\pi d^4/64$                   & \SI{1018}{\milli\metre\tothe{4}} \\
$W$   & Section modulus of a rod, $2I/d$                               & \SI{169.6}{\milli\metre\cubed} \\
$E$   & Young's modulus, hardened steel                                & \SI{207}{\giga\pascal} \\
$S_y$ & Yield strength of the rod                                      & \SI{350}{\mega\pascal} \\
$C_0$ & Static load rating of one linear bushing (LM12UU, catalogue)   & \SI{540}{\newton} \\
$C$   & Dynamic load rating of one linear bushing                      & \SI{390}{\newton} \\
\bottomrule
\end{tabular}
\end{center}

The rod diameter and the two spacings are read from the Delivery~2 carriage and
bearing-support drawings; the ratings are those of a standard LM12UU bushing and must be
replaced by the catalogue values of the type actually fitted before the result is used as
an acceptance criterion.

\section{Calculation model}\label{sec:gui-model}

The load case is \emph{not} assumed: it is the prismatic-joint reaction
$(\bm F_i,\bm M_i)$ that the static analysis of Sheet~2 already produced for every pose.
Splitting it along the travel axis $\bm u_i$,
\begin{equation}
\bm F_i = \underbrace{(\bm F_i\!\cdot\!\bm u_i)\,\bm u_i}_{\text{actuator, taken by the nut}}
        + \underbrace{\bm F_{t}}_{\text{transverse, taken by the bushings}},
\qquad
\bm M_i = \underbrace{(\bm M_i\!\cdot\!\bm u_i)\,\bm u_i}_{\text{roll}}
        + \underbrace{\bm M_{\perp}}_{\text{pitch and yaw}} .
\end{equation}

Each part is then reacted by a different feature of the carriage:

\begin{center}
\begin{tabular}{@{}l>{\raggedright\arraybackslash}p{5.9cm}l@{}}
\toprule
\textbf{Load} & \textbf{Reacted by} & \textbf{Bushing load} \\
\midrule
Transverse force $F_t$ & the four bushings together        & $F_t/4$ \\
Roll moment $M_{\parallel}$ & a couple between the two rods, lever arm $s$ & $M_{\parallel}/(2s)$ \\
Pitch/yaw moment $M_{\perp}$ & a couple between the two bushings of one rod, lever arm $b$ & $M_{\perp}/(2b)$ \\
\bottomrule
\end{tabular}
\end{center}

so that the worst bushing carries
\begin{equation}
F_{b} = \frac{F_t}{4} + \frac{M_{\parallel}}{2s} + \frac{M_{\perp}}{2b},
\qquad n_0 = \frac{C_0}{F_b}.
\label{eq:bushing}
\end{equation}
Superposing the three contributions on the same bushing is conservative: they reach their
maxima at slightly different poses.

The rod itself is treated as a simply supported beam of span $\ell$ with the carriage at
mid span, which is the worst position:
\begin{equation}
F_{r} = \frac{F_t}{2} + \frac{M_{\parallel}}{s},
\qquad
\delta = \frac{F_r\,\ell^{3}}{48EI},
\qquad
\sigma_b = \frac{F_r\,\ell}{4W}.
\end{equation}

\section{What the original sheet contained}\label{sec:gui-orig}

Nothing of the original \emph{Gu\'ias par R} sheet is dropped; it is relocated. That sheet
set out to determine, in its own words, the raising and lowering torque, the total torque,
the efficiency, the shear stress in torsion and the buckling --- all of them properties of
the \emph{lead screw}, not of the guides, and all of them already computed in Sheet~3.
The table below says where each of its objectives is answered and with what value.

\begin{center}\small
\begin{tabular}{@{}l>{\raggedright\arraybackslash}p{4.6cm}l l@{}}
\toprule
\textbf{Original objective} & \textbf{Answered in} & \textbf{Original value} & \textbf{Corrected value} \\
\midrule
Raising torque $T_s$        & Sheet 3, eq.~\eqref{eq:TR} & \SI{302.72}{\newton\milli\metre} & \SI{311.9}{\newton\milli\metre} \\
Lowering torque $T_d$       & Sheet 3, eq.~\eqref{eq:TL} & \SI{-94.39}{\newton\milli\metre} & \SI{-111.9}{\newton\milli\metre} \\
Collar torque $T_c$         & Sheet 3                    & \SI{27.342}{\newton\milli\metre} & \SI{9.7}{\newton\milli\metre} \\
Total raising torque        & Sheet 3                    & \SI{311.838}{\newton\milli\metre} & \SI{321.6}{\newton\milli\metre} \\
Total lowering torque       & Sheet 3                    & \SI{-67.048}{\newton\milli\metre} & \SI{-102.2}{\newton\milli\metre} \\
Efficiency                  & Sheet 3, eq.~\eqref{eq:eff} & 1.948 & \SI{64.1}{\percent} \\
Torsional shear             & Sheet 3                    & \SI{4.63}{\mega\pascal} & \SI{7.58}{\mega\pascal} \\
Thread shear                & Sheet 3                    & \SI{2379.96}{\mega\pascal} & \SI{3.77}{\mega\pascal} \\
Axial stress                & Sheet 3                    & \SI{72.21}{\mega\pascal} & \SI{5.73}{\mega\pascal} \\
Buckling $P_{cr}$           & Sheet 3                    & \SI{9428.8}{\newton} & \SI{519.9}{\newton} \\
Self-locking                & Sheet 3                    & not satisfied & not satisfied (confirmed) \\
\bottomrule
\end{tabular}
\end{center}

What follows is what that sheet was named after and never did: the verification of the
guides themselves.

\section{Results}\label{sec:gui-res}

\begin{center}
\begin{tabular}{@{}lcccc@{}}
\toprule
\textbf{Pose} & \textbf{Worst carriage} & $F_b$ [N] & $n_0=C_0/F_b$ & $\delta$ [mm] \\
\midrule
Home $(0,0,0)$         & 3 ($z$) & 188.5 & 2.86 & 0.141 \\
Corner $(+90,+90,+90)$ & 3 ($z$) & \textbf{288.6} & \textbf{1.87} & 0.146 \\
Corner $(-90,-90,-90)$ & 3 ($z$) & 143.2 & 3.77 & 0.128 \\
Corner $(+90,-90,+90)$ & 3 ($z$) & 282.8 & 1.91 & 0.154 \\
\bottomrule
\end{tabular}
\end{center}

\begin{center}
\begin{tabular}{@{}lccc@{}}
\toprule
\textbf{Worst pose, per carriage} & \textbf{Carriage 1 ($x$)} & \textbf{Carriage 2 ($y$)} & \textbf{Carriage 3 ($z$)} \\
\midrule
Transverse force $F_t$ [N]        & 23.6 & 23.6 & 0.0 \\
Pitch/yaw moment $M_{\perp}$ [N$\cdot$mm] & \num{24443} & \num{14059} & \num{34636} \\
Roll moment $M_{\parallel}$ [N$\cdot$mm]  & 0 & 0 & 0 \\
Worst bushing load $F_b$ [N]      & 209.6 & 123.1 & \textbf{288.6} \\
Rod deflection $\delta$ [mm]      & 0.146 & 0.146 & 0 \\
Rod bending stress $\sigma_b$ [MPa] & 8.7 & 8.7 & 0 \\
\bottomrule
\end{tabular}
\end{center}

\begin{center}
\begin{tabular}{@{}lcccccc@{}}
\toprule
Bushing spacing $b$ [mm] & 40 & \textbf{60 (as built)} & 80 & 100 & 120 \\
\midrule
Worst bushing load [N]   & 433.0 & \textbf{288.6} & 216.5 & 173.2 & 144.3 \\
Static safety factor     & 1.25  & \textbf{1.87}  & 2.49  & 3.12  & 3.74 \\
\bottomrule
\end{tabular}
\end{center}

\begin{figure}[htbp]\centering

\caption{Guide verification: load on the most loaded bushing of each carriage, where that
load comes from, and how it depends on the bushing spacing.}
\end{figure}
\FloatBarrier

\section{Conclusions}\label{sec:gui-conc}

\begin{enumerate}[leftmargin=*]
  \item \textbf{The guides carry the tightest margin in the whole machine.} With a static
        safety factor of \textbf{1.87} against the rating of an LM12UU bushing, the
        guides are more critical than the buckling of the lead screw (3.21), than the arms
        (9.6), than the screw body (25.8) and than the frame (66). Any review of this
        design should start here, not at the screw.
  \item \textbf{The load is almost entirely a moment, not a force.} On the vertical
        carriage the transverse force is zero and the whole \SI{289}{\newton} comes from
        the \SI{34.6}{\newton\metre} pitch moment that the two arms apply to the carriage.
        This is the structural signature of a Tripteron: the arms reach out from the
        carriage, so what the guide has to resist is the lever, not the cut.
  \item \textbf{The governing parameter is the bushing spacing $b$, not the rod
        diameter.} Equation~\eqref{eq:bushing} makes the moment term inversely
        proportional to $b$: moving the two bushings from \SI{60}{\milli\metre} to
        \SI{100}{\milli\metre} apart raises the safety factor from 1.87 to 3.12 at
        no cost in material. Increasing the rod diameter instead would do nothing for the
        bushing load at all. If one change is made to this machine, this is the one.
  \item \textbf{The rods are stiff enough but they dominate the machine's compliance.}
        Their bending stress is \SI{8.7}{\mega\pascal} against \SI{350}{\mega\pascal}
        (safety factor 40), so strength is irrelevant; but their worst mid-span deflection
        of \SI{0.154}{\milli\metre} is larger than the \SI{0.102}{\milli\metre} of the
        whole welded frame (Sheet~5). Guides and frame together give roughly
        \SI{0.26}{\milli\metre}, which still meets the \SI{1}{\milli\metre} accuracy
        requirement of Delivery~1, but the guides --- not the chassis --- are where the
        accuracy is lost.
\end{enumerate}

%==============================================================================
\sheet{Sheet 5 -- Chassis finite element verification}{D. Zuluaga}
%==============================================================================
\section{Description}\label{sec:fea-desc}

The three legs are mounted on a welded frame of square steel tubing that also carries the
work table. The frame is the one component whose behaviour cannot be captured by a hand
calculation: it is a three-dimensional redundant structure, so it was verified by finite
elements in SolidWorks Simulation.

This sheet keeps the original study in full --- its model, its loads, its nine result plots
and its conclusions --- and adds to it the post-processing of the exported nodal data, so
that every number quoted here is reproducible from the files in the repository rather than
read off a screenshot. The raw exports live in
\texttt{04\_Calculations/data/fea\_exports/} and are processed by
\texttt{tripteron/fea\_postprocess.py}.

\section{Objective of the calculation}\label{sec:fea-obj}

\begin{enumerate}[leftmargin=*,nosep]
  \item Verify that the frame stays in the elastic range under the weight of the three
        axis assemblies and the reactions of Sheet~2.
  \item Verify that its deflection is small compared with the machining tolerance.
  \item Verify the frame against global buckling.
\end{enumerate}

\section{Variables of the calculation model}\label{sec:fea-var}

\begin{center}
\begin{tabular}{@{}cl c@{}}
\toprule
\textbf{Symbol} & \textbf{Description} & \textbf{Value} \\
\midrule
$F_1$ & Total weight carried by axis 1 & \SI{9.762}{\kilo\gram} = \SI{95.75}{\newton} \\
$F_2$ & Total weight carried by axis 2 & \SI{9.762}{\kilo\gram} = \SI{95.75}{\newton} \\
$F_3$ & Total weight carried by axis 3 & \SI{9.762}{\kilo\gram} = \SI{95.75}{\newton} \\
$P_m$ & Mass of one NEMA 34 motor      & \SI{5.216}{\kilo\gram} \\
$P_t$ & Mass of one lead screw         & \SI{1.120}{\kilo\gram} \\
$P_g$ & Mass of one linear guide       & \SI{2.530}{\kilo\gram} \\
$P_h$ & Mass of one arm                & \SI{0.322}{\kilo\gram} \\
$P_e$ & Mass of the end effector       & \SI{0.574}{\kilo\gram} \\
\bottomrule
\end{tabular}
\end{center}

All masses were read from the SolidWorks physical-properties tool; each axis load is the
sum of the components that rest on that beam, so they carry a small approximation error.

\section{Image of the calculation model}\label{sec:fea-img}

\begin{figure}[htbp]\centering
\begin{minipage}[t]{0.47\textwidth}\centering
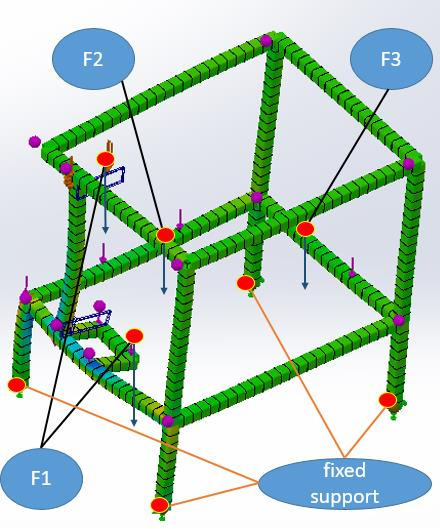
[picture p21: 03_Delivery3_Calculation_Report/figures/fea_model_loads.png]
\\[3pt]
{\footnotesize Applied forces and fixed supports}
\end{minipage}\hfill
\begin{minipage}[t]{0.47\textwidth}\centering
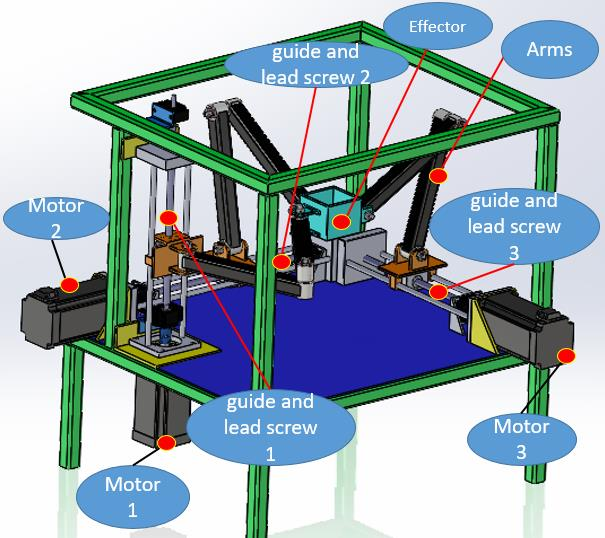
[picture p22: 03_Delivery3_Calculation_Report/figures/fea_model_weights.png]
\\[3pt]
{\footnotesize Components whose weight loads the frame}
\end{minipage}
\caption{Calculation model: the four fixed feet, the three axis loads and the components
whose weight produces them.}
\end{figure}
\FloatBarrier

\section{Values and calculation model}\label{sec:fea-model}

\begin{center}
\begin{tabular}{@{}l>{\raggedright\arraybackslash}p{10.6cm}@{}}
\toprule
Geometry          & Chassis CAD at full size, welded tubular frame \\
Element type      & Beam elements \\
Material          & Alloy steel, $E=\SI{210}{\giga\pascal}$, $S_y=\SI{620}{\mega\pascal}$ \\
Interaction       & Global interaction, rigid joints, independent meshing \\
Fixation          & Four fixed restraints, one per foot \\
External loads    & Three forces of \SI{95.75}{\newton} on their respective beams \\
Mesh              & Curvature-based mesh, standard density \\
Studies           & Linear static analysis and linear (eigenvalue) buckling analysis \\
Post-processing   & Nodal values read with \emph{identify values} on the loaded faces and
                    exported to CSV \\
\bottomrule
\end{tabular}
\end{center}

Beam elements are the right idealisation here: the frame is made of slender tubes loaded
mainly in bending and axial force and welded at the nodes, and a beam model reproduces
that behaviour with a fraction of the degrees of freedom of a solid mesh. Local weld
stresses are not captured and are covered by the weld sizing of Delivery~2.

\subsection{Scope of the load case}

The load applied in the finite element model is the \emph{self weight} of the three axis
assemblies, \SI{95.75}{\newton} each. It does not include the cutting force, whose
reactions were only obtained later, in Sheet~2. Those reactions reach
\SI{162}{\newton} on the vertical axis, i.e.\ \SI{69}{\percent} more than the weight
already applied on that beam. Because the static safety factor of the frame is 66, adding
them cannot bring the structure anywhere near its limit; the deflection, however, would
grow roughly in proportion, so the \SI{0.102}{\milli\metre} below should be read as the
figure for a machine at rest and about \SI{0.17}{\milli\metre} while cutting.

\section{Results of the calculation model}\label{sec:fea-res}

\subsection{Static analysis}

\begin{figure}[htbp]\centering
\begin{minipage}[t]{0.47\textwidth}\centering
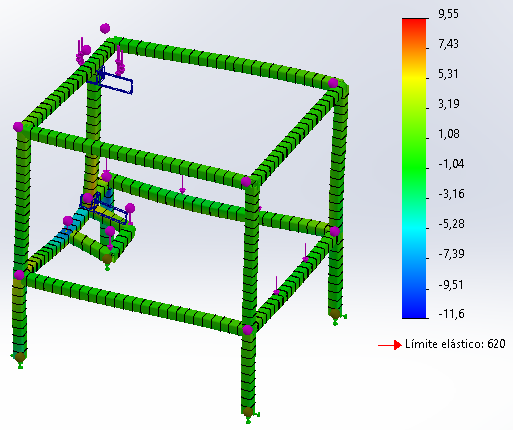
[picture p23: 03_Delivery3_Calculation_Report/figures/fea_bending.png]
\\[2pt]{\footnotesize Bending stress [MPa]}
\end{minipage}\hfill
\begin{minipage}[t]{0.47\textwidth}\centering
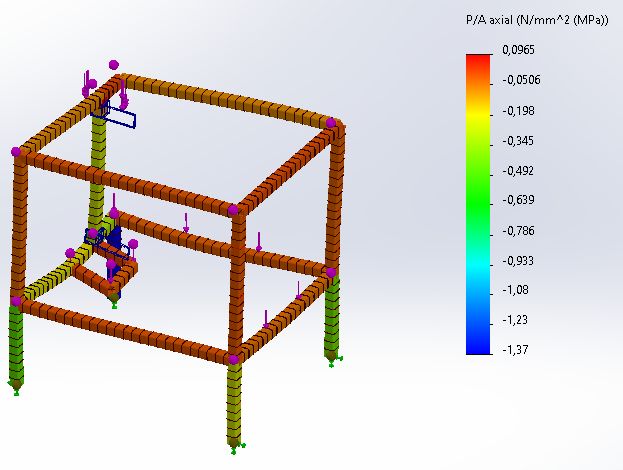
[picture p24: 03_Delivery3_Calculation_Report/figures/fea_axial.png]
\\[2pt]{\footnotesize Axial stress [MPa]}
\end{minipage}

\vspace{8pt}
\begin{minipage}[t]{0.47\textwidth}\centering
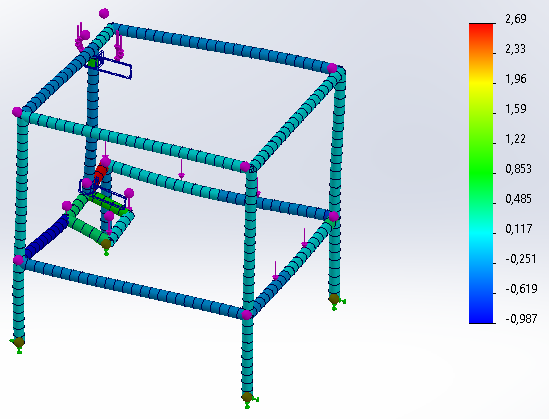
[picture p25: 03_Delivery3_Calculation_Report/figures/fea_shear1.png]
\\[2pt]{\footnotesize Shear stress, direction 1 [MPa]}
\end{minipage}\hfill
\begin{minipage}[t]{0.47\textwidth}\centering
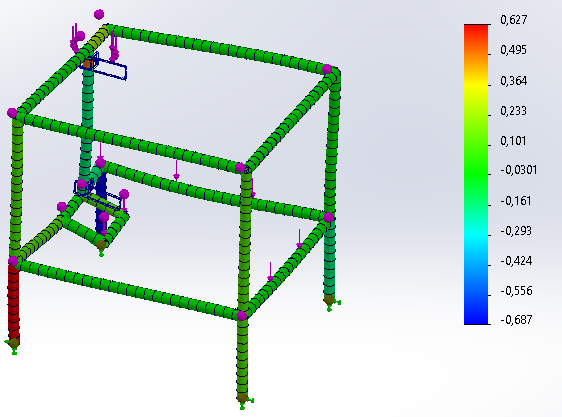
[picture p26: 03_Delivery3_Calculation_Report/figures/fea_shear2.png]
\\[2pt]{\footnotesize Shear stress, direction 2 [MPa]}
\end{minipage}

\vspace{8pt}
\begin{minipage}[t]{0.47\textwidth}\centering
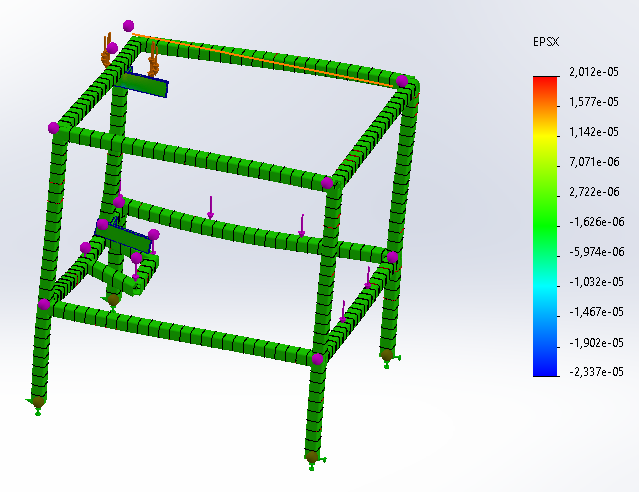
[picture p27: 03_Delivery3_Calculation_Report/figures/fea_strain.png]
\\[2pt]{\footnotesize Strain [--]}
\end{minipage}\hfill
\begin{minipage}[t]{0.47\textwidth}\centering
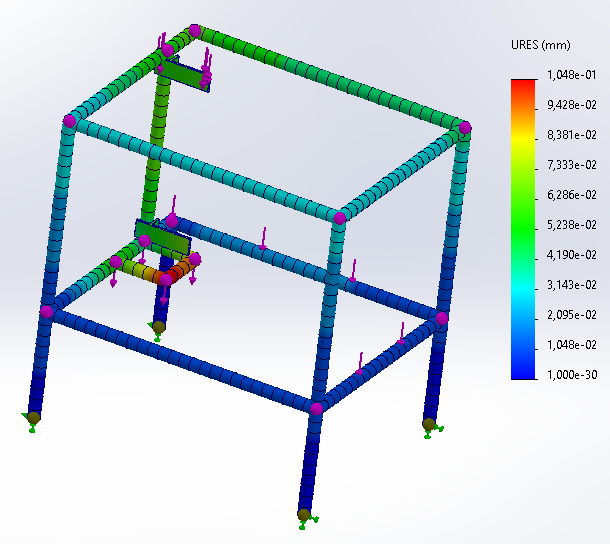
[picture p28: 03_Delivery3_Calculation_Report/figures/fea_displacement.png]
\\[2pt]{\footnotesize Resultant displacement [mm]}
\end{minipage}
\caption{Static analysis of the chassis: stress components, strain and displacement.}
\end{figure}
\FloatBarrier

\subsection{Buckling analysis}

\begin{figure}[htbp]\centering
\begin{minipage}[t]{0.32\textwidth}\centering
\\[2pt]{\footnotesize Mode 1, amplitude $x$ [mm]}
\end{minipage}\hfill
\begin{minipage}[t]{0.32\textwidth}\centering
\\[2pt]{\footnotesize Mode 1, amplitude $y$ [mm]}
\end{minipage}\hfill
\begin{minipage}[t]{0.32\textwidth}\centering
\\[2pt]{\footnotesize Mode 1, amplitude $z$ [mm]}
\end{minipage}
\caption{First buckling mode of the frame: a lateral sway of the uprights.}
\end{figure}
\FloatBarrier

\subsection{Exported values}

The nodal values read on the loaded faces were exported and post-processed by
\texttt{fea\_postprocess.py}; the table below replaces the nine value tables of the
original study with a single one, and the figure replaces its nine graphs.

\begin{center}
\begin{tabular}{@{}lrrrr@{}}
\toprule
\textbf{Quantity} & \textbf{Samples} & \textbf{Minimum} & \textbf{Maximum} & $\lvert\cdot\rvert_{\max}$ \\
\midrule
Bending stress [MPa]        & 19 & $-9.36$   & $-0.574$  & 9.36 \\
Axial stress [MPa]          & 33 & $-0.305$  & $0.0029$  & 0.305 \\
Shear stress, dir.\ 1 [MPa] & 40 & $-0.987$  & $2.69$    & 2.69 \\
Shear stress, dir.\ 2 [MPa] & 31 & $-0.219$  & $0.627$   & 0.627 \\
Strain [--]                 & 23 & $-6.4\times10^{-6}$ & $2.9\times10^{-6}$ & $6.4\times10^{-6}$ \\
Displacement [mm]           & 22 & $0$       & $0.1016$  & 0.1016 \\
Buckling mode 1, $x$ [mm]   & 27 & $0$       & $0.0285$  & 0.0285 \\
Buckling mode 1, $y$ [mm]   & 24 & $-0.0035$ & $0.0035$  & 0.0035 \\
Buckling mode 1, $z$ [mm]   & 21 & $-0.0213$ & $0.0019$  & 0.0213 \\
\bottomrule
\end{tabular}
\end{center}

\begin{center}
\begin{tabular}{@{}lc@{}}
\toprule
\textbf{Verification} & \textbf{Result} \\
\midrule
Governing stress                  & bending, \SI{9.36}{\mega\pascal} \\
Yield strength                    & \SI{620}{\mega\pascal} \\
\textbf{Static safety factor}     & \textbf{66} \\
Maximum displacement              & \SI{0.102}{\milli\metre} \\
\textbf{Buckling load factor}     & \textbf{2238} \\
\bottomrule
\end{tabular}
\end{center}

\begin{figure}[htbp]\centering

\caption{Range of each exported quantity and the resulting margins.}
\end{figure}
\FloatBarrier

\section{Results and conclusions of the calculation model}\label{sec:fea-conc}

\begin{enumerate}[leftmargin=*]
  \item \textbf{The frame is massively over-strength.} A safety factor of 66 against yield
        and a buckling load factor of 2238 mean the structure is nowhere near its strength
        limit. This is not an error: the frame was sized by \emph{stiffness} and by the
        commercial tube sizes available, not by stress. In a machine tool the deflection
        under load is what shows up on the part, and it is always the binding requirement.
  \item \textbf{Stiffness is the meaningful result.} The maximum displacement of
        \SI{0.102}{\milli\metre} occurs at the top rail, furthest from the feet. Referred
        to the \SI{200}{\milli\metre} workspace this is \SI{0.05}{\percent}, and it is of
        the same order as the positioning resolution of the drives. It is acceptable for
        the intended use (light milling of aluminium and plastics), but it is one of the
        two numbers that limit the achievable accuracy of the machine --- the other being
        the \SI{0.154}{\milli\metre} of the guide rods in Sheet~4, which is larger.
  \item \textbf{The dominant stress is bending}, an order of magnitude above the axial and
        shear components. The load path is therefore what one would expect: the reactions
        of the legs are applied off the neutral axis of the rails and are carried in
        bending to the feet. If the frame were ever to be lightened, the rails in bending
        are what must be preserved; the diagonal members carry little load.
  \item \textbf{Global buckling is irrelevant} for this structure at this load level. The
        first mode is a lateral sway of the uprights, and it would require 2238 times the
        service load to occur.
  \item \textbf{The load case can be tightened.} Rerunning the study with the joint
        reactions of Sheet~2 instead of the bare self weight would not change any
        conclusion, but it would give a deflection figure valid while cutting. That is the
        one change worth making to this study.
\end{enumerate}

%==============================================================================
\sheet{Appendix A -- Corrections}{Group 2}
%==============================================================================
\section{Corrections to the previous calculation memo}\label{sec:corrections}

The earlier version of this memo contained a number of results that cannot be correct on
physical grounds. Each of them is listed below with the reason it is wrong and the value
that replaces it. All the replacement values come from the recomputation documented in
Sheets 1--5. The page references are to the original submission,
\texttt{MemoriaCalculosGrupo2Maquinas1.pdf}, dated 25 May 2024.

\renewcommand{\arraystretch}{1.25}
\begin{longtable}{@{}p{0.5cm}>{\raggedright\arraybackslash}p{3.9cm}>{\raggedright\arraybackslash}p{4.7cm}>{\raggedright\arraybackslash}p{4.9cm}@{}}
\toprule
\textbf{\#} & \textbf{Previous result} & \textbf{Why it cannot be right} & \textbf{Corrected value} \\
\midrule
\endhead
\multicolumn{4}{@{}l}{\textbf{A. Two sheets for the same screw}}\\
\midrule
1 & The sheets \emph{Tornillo de potencia} (pp.~23--29) and \emph{Gu\'ias par R}
    (pp.~30--37) calculate the same screw and disagree on every line
  & Same formulas, different arithmetic. $T_c$: 9.114 vs.\ \SI{27.342}{\newton\milli\metre};
    $T_{\text{lower}}$: $-85.271$ vs.\ $-67.048$; $e$: 0.6202 vs.\ 1.948;
    $\sigma_a$: 3.438 vs.\ \SI{72.21}{\mega\pascal};
    $\tau_{\text{thread}}$: 0.1958 vs.\ \SI{2379.96}{\mega\pascal};
    $P_{cr}$: 93.06 vs.\ \SI{9428.8}{\newton}. At most one of each pair could be right; in
    fact both are, because the formulas themselves are wrong.
  & One screw, one sheet: Sheet~3, with $T_R=\SI{321.6}{\newton\milli\metre}$,
    $e=\SI{64.1}{\percent}$, $\sigma_a=\SI{5.73}{\mega\pascal}$,
    $\tau_{\text{thread}}=\SI{3.77}{\mega\pascal}$, $P_{cr}=\SI{519.9}{\newton}$ \\
2 & The guides themselves were never verified: the sheet titled \emph{Gu\'ias par R}
    repeats the screw calculation
  & The whole point of that sheet --- can the bushings and rods take the moment the arms
    apply to the carriage? --- is never asked.
  & New Sheet~4. The guides turn out to hold the \emph{tightest} margin of the machine,
    $n_0=1.87$ \\
\midrule
\multicolumn{4}{@{}l}{\textbf{B. Lead screw}}\\
\midrule
3 & $e_{\text{ascenso}} = 1.948$ (p.~35)
  & Efficiency above 1 would create energy. The expression was inverted, and $2$ was used
    where $2\pi$ belongs.
  & $e=FL/(2\pi T_R)=\SI{64.1}{\percent}$ \\
4 & $T = P\,\frac{d_p}{2}\,d_p\cos\theta\,f$ (pp.~25, 33)
  & Dimensionally inconsistent: it returns \si{\newton\milli\metre\squared}. It is not the
    power-screw relation, and it contains neither the lead nor the sign change between
    raising and lowering.
  & Shigley, equations~\eqref{eq:TR} and~\eqref{eq:TL} \\
5 & $T_c = \SI{27.342}{\newton\milli\metre}$ (p.~34)
  & $T_c=\mu_c F d_c/2$ with $d_c=\SI{6}{\milli\metre}$ gives a lever of
    \SI{3}{\milli\metre}, not \SI{9}{\milli\metre}. The other sheet got this one right.
  & $T_c = \SI{9.72}{\newton\milli\metre}$ at the corrected design load \\
6 & Thread shear \SI{2379.96}{\mega\pascal} (p.~36)
  & Six times the yield strength of any screw steel. The shear area was written as
    $(d_r w)^2/4A w$, which is not an area of anything.
  & $\tau=2F/(\pi d_r w p\,n_t)=\SI{3.77}{\mega\pascal}$, $n_{\text{thread}}=56.6$ \\
7 & $\sigma_a = 16 P (d_p+d_r)^2/(\pi d_r^4)$, giving \SI{3.438}{\mega\pascal} on p.~28
    and \SI{72.21}{\mega\pascal} on p.~35
  & That is a bending expression, not an axial one; an axial stress is force over area.
    Evaluated correctly the wrong formula gives \SI{72.2}{\mega\pascal}, so the
    \SI{3.438}{\mega\pascal} is also an arithmetic slip.
  & $\sigma_a=F/A_r=\SI{5.73}{\mega\pascal}$ \\
8 & $P_{cr}=2EI/\ell^2$ with $E=\SI{20000}{\mega\pascal}$, giving \SI{93.06}{\newton}
    (p.~29) and \SI{9428.8}{\newton} (p.~37)
  & The Euler load is $\pi^2EI/(K\ell)^2$, and steel has $E=\SI{207000}{\mega\pascal}$.
    The two answers differ by a factor of exactly 100, so at least one is also an
    arithmetic slip.
  & $P_{cr}=\pi^2EI/(K\ell)^2=\SI{519.9}{\newton}$, $n=3.21$ \\
9 & Slenderness $S_r=\ell/(I/A)=285.7$ with $A=4\pi d_r^2$ (p.~29)
  & Slenderness is $\ell/r_g$ with $r_g=\sqrt{I/A}$, and the area of a circle is
    $\pi d_r^2/4$, not $4\pi d_r^2$. The value was never used to choose between the Euler
    and the Johnson regime.
  & $\ell/r_g=333$ against a transition of 105 $\Rightarrow$ Euler regime \\
10 & $p=\SI{4}{\milli\metre}$ with 2 starts, yet $d_r=\SI{7}{\milli\metre}$ throughout
   & The two are incompatible: $d_r=d-p$ gives \SI{4}{\milli\metre} for $p=4$. A root
     diameter of \SI{7}{\milli\metre} corresponds to $p=\SI{2}{\milli\metre}$, which is
     the screw actually fitted.
   & Tr8$\times$8(P2), 4 starts: $p=\SI{2}{\milli\metre}$, $L=\SI{8}{\milli\metre}$,
     $d_m=\SI{7}{\milli\metre}$, $d_r=\SI{6}{\milli\metre}$ \\
11 & Self-locking claimed for the vertical axis
   & Consequence of \#10. A 4-start screw with $\mu=0.15$ cannot be self-locking.
   & Not self-locking; a brake or permanent holding current is required on $z$ \\
\midrule
\multicolumn{4}{@{}l}{\textbf{C. Statics}}\\
\midrule
12 & ``27 equations and 27 unknowns'', ``8 bars with 9 binary revolute pairs'' (p.~3)
   & The machine has 10 moving bodies and 12 joints. The three prismatic joints were left
     out of the model altogether.
   & 60 equations, 63 unknowns, rank 60, 3 redundant reactions \\
13 & The actuator forces never appear in the results (p.~7)
   & They are the reason a static analysis is done at all: without them the screw and the
     motor cannot be sized. Leaving the prismatic joints out of the model removed them.
   & $F_x=F_y=\SI{-80.9}{\newton}$, $F_z=\SI{+157.9}{\newton}$ at home; design load
     \SI{162.0}{\newton} \\
14 & Reactions of 0 to \SI{10}{\newton}, most of them exactly zero (p.~7)
   & A \SI{120}{\newton} cutting force cannot produce \SI{5.77}{\newton} of reaction. An
     all-zero solution is the trivial solution of a system assembled without its load
     vector.
   & Residual below \SI{3e-9}{\newton}, cross-checked by virtual work \\
15 & Cutting force applied upwards
   & An end mill pushes the work downwards against the table; applied upwards it cancels
     part of the weight of the moving assembly and under-predicts the load on the vertical
     screw.
   & $\bm F_c=[80,80,-120]^{\mathsf T}$\,\si{\newton} $\Rightarrow$ design load
     \SI{162.0}{\newton} instead of \SI{85}{\newton} \\
\midrule
\multicolumn{4}{@{}l}{\textbf{D. Kinematics and presentation}}\\
\midrule
16 & No verification of the kinematic solution
   & A position solution with no residual and no independent check cannot be audited.
   & Newton--Raphson residual below \SI{8e-11}{\milli\metre}, agreement with the
     closed-form inverse kinematics to $10^{-13}$\,mm, velocities and accelerations
     checked against finite differences \\
17 & The chassis sheet (pp.~38--60) carries no date and no reviewer
   & An unsigned, undated calculation sheet cannot be released.
   & Every sheet of this edition carries project, calculation, analyst, reviewer, date and
     page \\
\bottomrule
\end{longtable}
\renewcommand{\arraystretch}{1}

\subsection{Effect of the corrections on the design}

None of the corrections invalidates the machine. The two that matter in practice are:

\begin{itemize}[leftmargin=*,nosep]
  \item \textbf{Correction 8} raises the design axial load from \SI{85}{\newton} to
        \SI{162.0}{\newton}. The screw still passes every check, but the buckling safety
        factor drops from about 6 to 3.21, which is why the column check --- and not the
        stress check --- is now the governing criterion for the transmission.
  \item \textbf{Correction 11} changes an operating requirement: the vertical axis is not
        self-locking and needs a brake or a permanently energised motor. This is a safety
        item that the previous memo did not identify.
  \item \textbf{Correction 2} changes where the attention should go. Because the sheet
        that was supposed to verify the guides verified the screw instead, nobody ever
        computed the load on the bushings. It turns out to be the tightest margin in the
        machine ($n_0=1.87$), and it is fixed by moving two bushings further apart --- the
        cheapest change available anywhere in this design.
\end{itemize}

%==============================================================================
\sheet{Appendix B -- Calculation software}{Group 2}
%==============================================================================
\section{Reproducing the results}\label{sec:software}

Every figure and every number in this report is generated by the Python package stored
in the folder \texttt{04\_Calculations}. A single command regenerates all of them:

\begin{center}\ttfamily
python run\_all.py
\end{center}

The script creates its own virtual environment on first use, installs the dependencies and
writes the results to \texttt{results/} (CSV and JSON) and \texttt{figures/} (PNG).
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

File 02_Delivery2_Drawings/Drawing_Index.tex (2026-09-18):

\documentclass[11pt]{article}
\usepackage[english]{babel}
\usepackage[utf8]{inputenc}
\usepackage{lmodern}
\usepackage[T1]{fontenc}
\usepackage{graphicx}
\usepackage{booktabs}
\usepackage{array}
\usepackage{longtable}
\usepackage{enumitem}
\usepackage{amssymb}
\usepackage{siunitx}
\usepackage[table]{xcolor}
\usepackage[left=2.3cm,right=2.3cm,top=2.6cm,bottom=2.3cm]{geometry}
\usepackage{fancyhdr}
\usepackage{titlesec}
\usepackage[hidelinks]{hyperref}
\definecolor{eafitblue}{HTML}{16436f}
\titleformat{\section}{\normalfont\large\bfseries\color{eafitblue}}{\thesection.}{0.6em}{}[{\titlerule[0.6pt]}]
\setlength{\parskip}{4pt}\setlength{\parindent}{0pt}
\pagestyle{fancy}\fancyhf{}
\renewcommand{\headrulewidth}{0.4pt}
\fancyhead[L]{\small\textsc{Tripteron CNC router -- Drawing package}}
\fancyhead[R]{\small IM0240 Machine Design I}
\fancyfoot[C]{\small\thepage}

\begin{document}
\thispagestyle{empty}
\begin{center}
\vspace*{1cm}
{\Large\scshape Universidad EAFIT}\\[3pt]
{\large School of Applied Sciences and Engineering}\\[3pt]
{\large Department of Mechanical Engineering}\\[3pt]
{\large IM0240 -- Machine Design I}\\[1.8cm]

{\color{eafitblue}\rule{\textwidth}{1.4pt}}\\[12pt]
{\huge\bfseries Drawing package}\\[8pt]
{\LARGE Tripteron CNC router machine}\\[10pt]
{\large\bfseries Delivery 2 -- English cover and drawing index}\\[8pt]
{\color{eafitblue}\rule{\textwidth}{1.4pt}}\\[2cm]

{\large\bfseries Group 2}\\[8pt]
{\large David Amell Osorio}\\[4pt]
{\large Ronny Antonio Bueno}\\[4pt]
{\large Juan Jos\'e Garc\'ia}\\[4pt]
{\large Germ\'an Gabriel Ria\~no Barrera}\\[4pt]
{\large Sebasti\'an Rinc\'on Mart\'inez}\\[4pt]
{\large Juan Manuel Rodr\'iguez Duque}\\[4pt]
{\large David Zuluaga Henao}\\[1.4cm]

{\large\bfseries Course lecturer}\\[8pt]
{\large Juan Andr\'es Gallego S\'anchez}
\vfill
{\large Medell\'in, Colombia -- 3 March 2024}
\end{center}

\clearpage
\section{About this package}
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

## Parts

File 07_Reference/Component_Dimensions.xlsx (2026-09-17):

Gay el que lea | Componentes | Largo [cm] | Dimensiones componente | Cantidad | Material
CHASIS | Tubería 1" |  | 1" |  | Acero
 | Tubería 1" |  | 1" |  | Acero
 | Tubería 1" |  | 1" |  | Acero

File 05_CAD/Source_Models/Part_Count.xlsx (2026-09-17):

Pieza | Cantidad | Material | Dimensiones (mm) | Total
Tubería Cuadrada 25mm | 6 | Acero | 25x25x250
Tubería Cuadrada
Tornillos
Lámina de Acero | 1

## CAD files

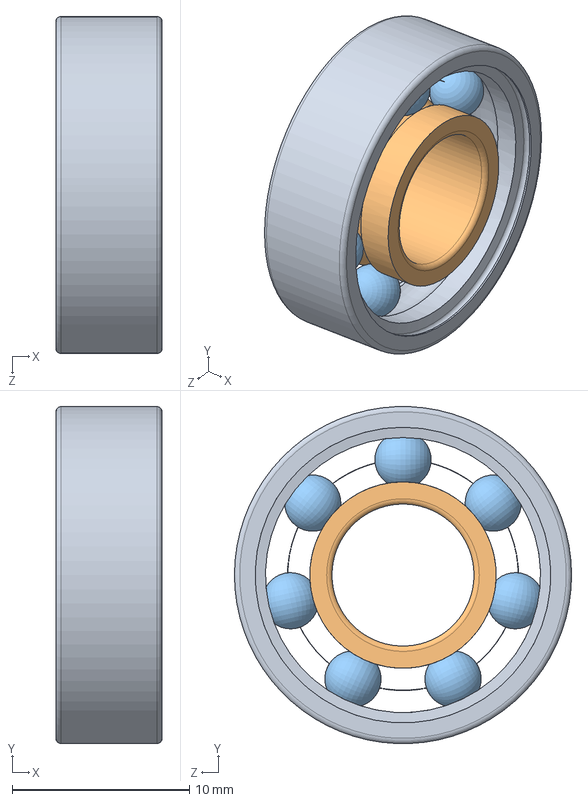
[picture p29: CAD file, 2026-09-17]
05_CAD/Final_CAD/R_Pair/cads/skf_bearing_619_8_2.SLDASM
6.00 x 19.0 x 19.0 mm
skf_bearing_619_8_2_01
skf_bearing_619_8_2_02
skf_bearing_619_8_2_03

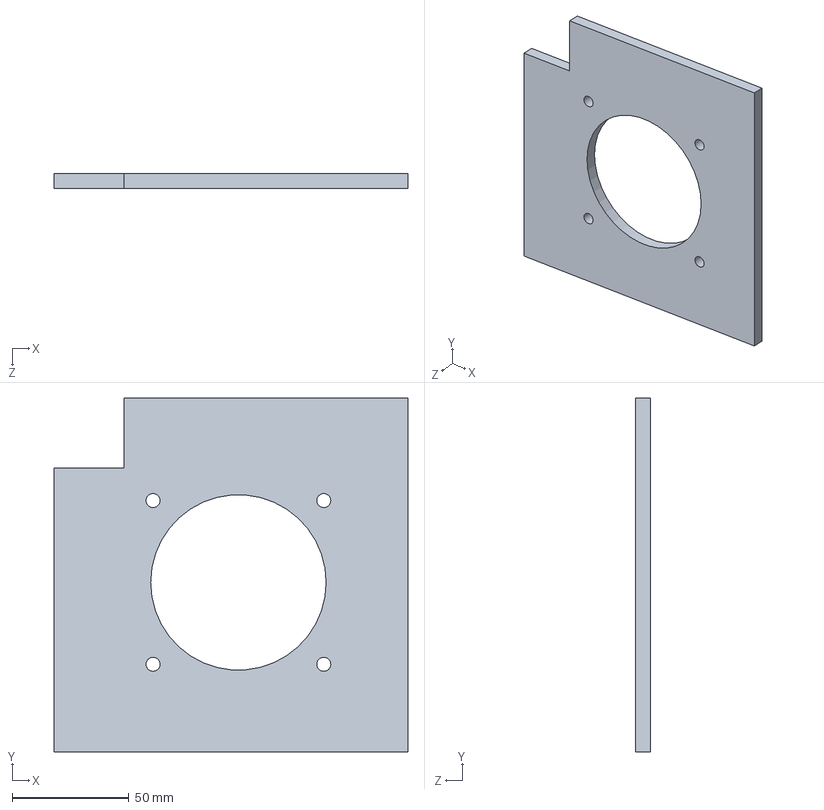
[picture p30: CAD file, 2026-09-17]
05_CAD/Final_CAD/Machine/Maquina/Lamina-CuartoDePulgada.SLDPRT
151.4 x 151.4 x 6.35 mm

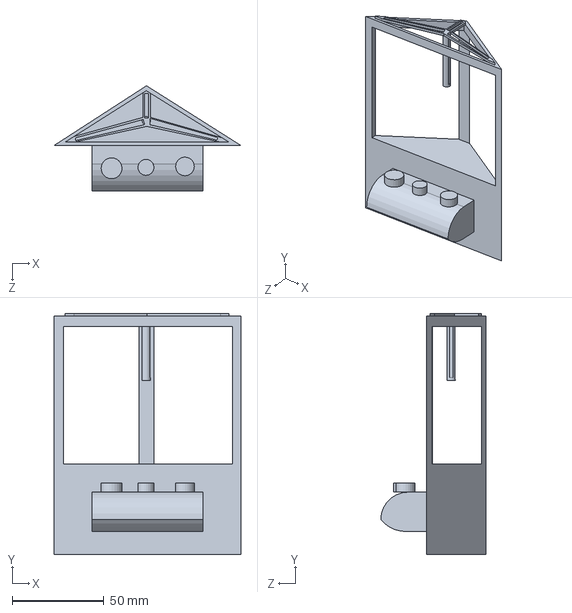
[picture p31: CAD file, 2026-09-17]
05_CAD/Source_Models/Concept_Proposals/propuesta maquinas 1.SLDPRT
101.9 x 131.5 x 57.6 mm

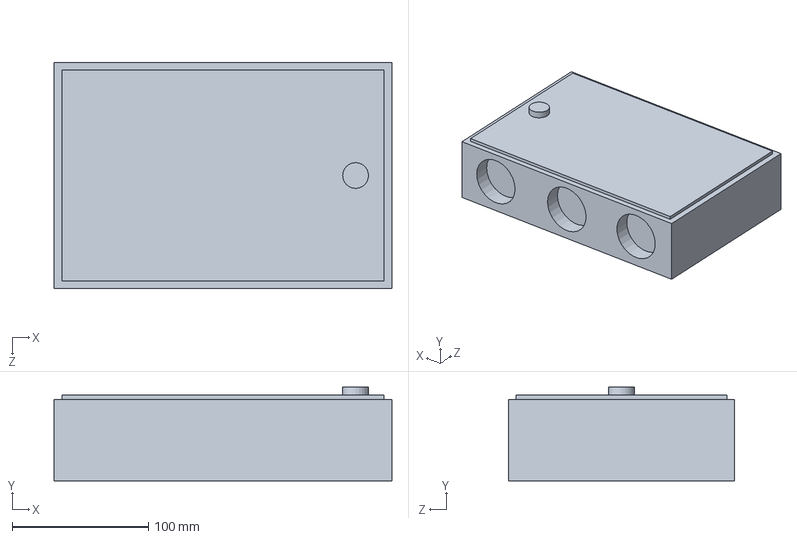
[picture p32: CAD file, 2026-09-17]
05_CAD/Source_Models/Drawings_Electrical/Caja sistema elecrico.SLDPRT
248.1 x 69.0 x 165.7 mm

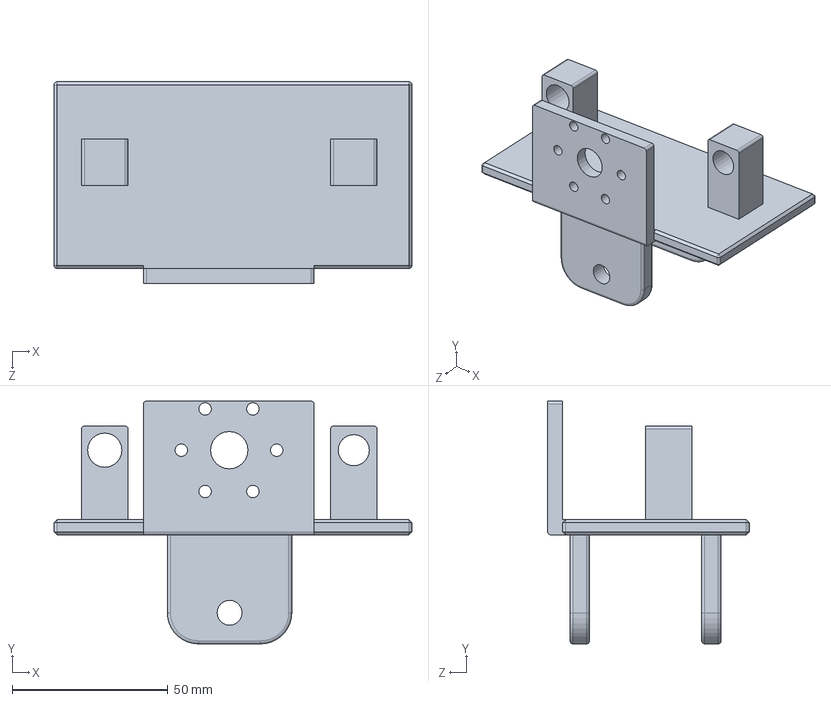
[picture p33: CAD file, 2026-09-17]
05_CAD/Final_CAD/Machine/Maquina/carrito guia.SLDPRT
115.0 x 78.0 x 64.8 mm

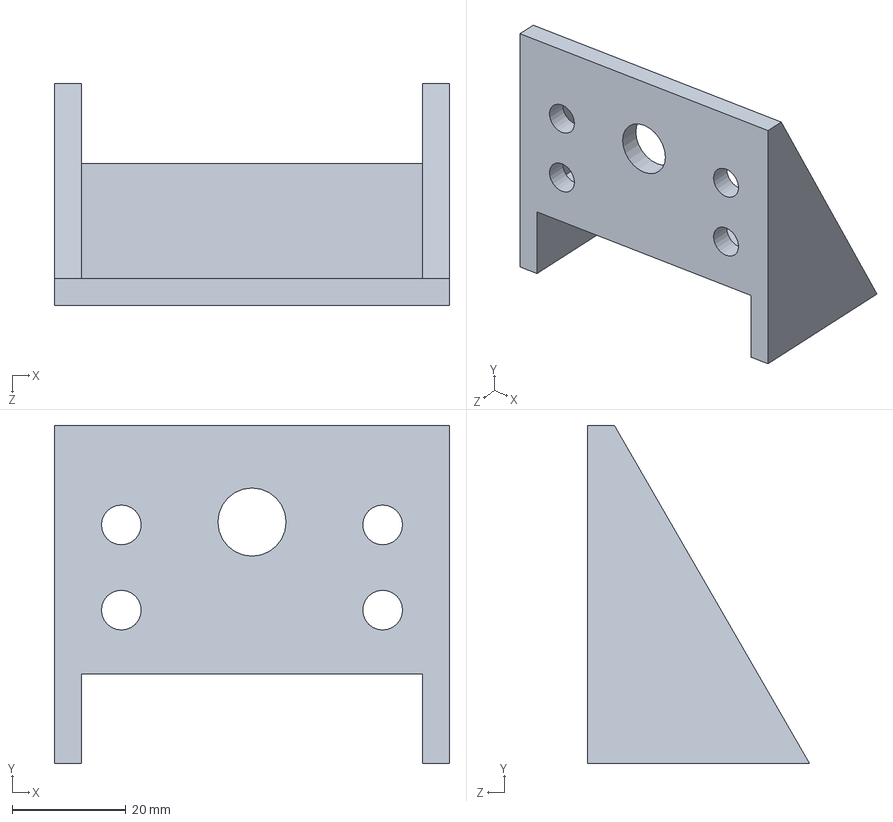
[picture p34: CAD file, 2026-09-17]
05_CAD/Final_CAD/Machine/Maquina/SoporteLadoMotor.SLDPRT
69.5 x 59.5 x 39.1 mm

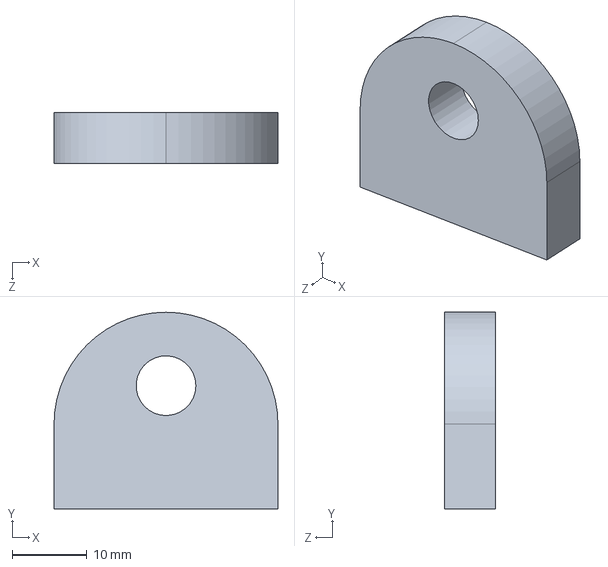
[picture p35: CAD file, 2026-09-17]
05_CAD/Final_CAD/R_Pair/PLANOS SUBENSAMBLE Y COMPONENTE/fdsfssddfsfs.SLDPRT
30.0 x 26.3 x 6.80 mm

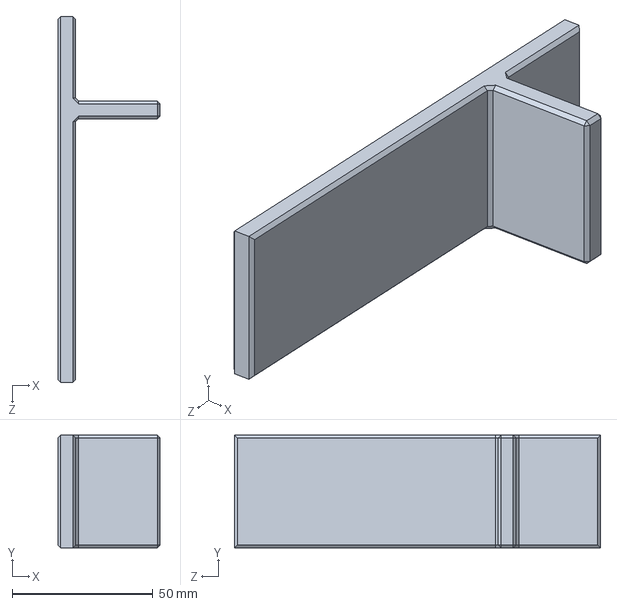
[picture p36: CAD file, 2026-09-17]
05_CAD/Final_CAD/Machine/Maquina/Soporte1Top.SLDPRT
36.3 x 40.0 x 130.0 mm

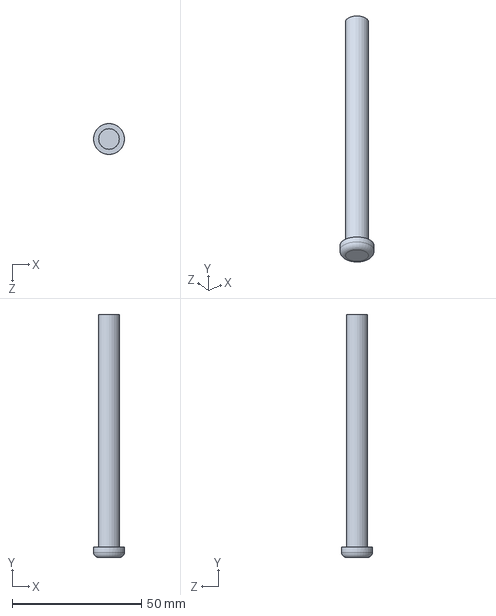
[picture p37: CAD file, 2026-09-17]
05_CAD/Final_CAD/Machine/PLANOS/Pieza5.SLDPRT
12.0 x 94.0 x 12.0 mm

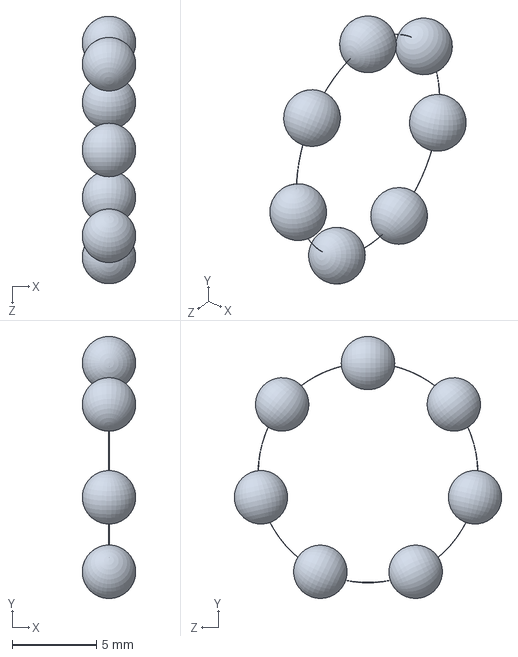
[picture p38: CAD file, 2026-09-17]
05_CAD/Final_CAD/R_Pair/cads/skf_bearing_619_8_2_03.SLDPRT
3.16 x 15.5 x 15.8 mm

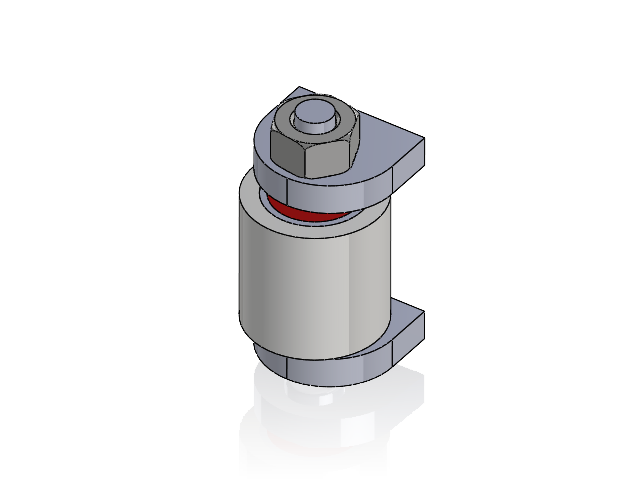
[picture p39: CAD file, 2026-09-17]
05_CAD/Final_CAD/R_Pair/PLANOS SUBENSAMBLE Y COMPONENTE/parR2.SLDASM
Pieza1
rodamiento 8 mm x 2
Pieza3
ISO 4032 Nut M10.step
Pieza6sep x 2
Eje2
fdsfssddfsfs x 2

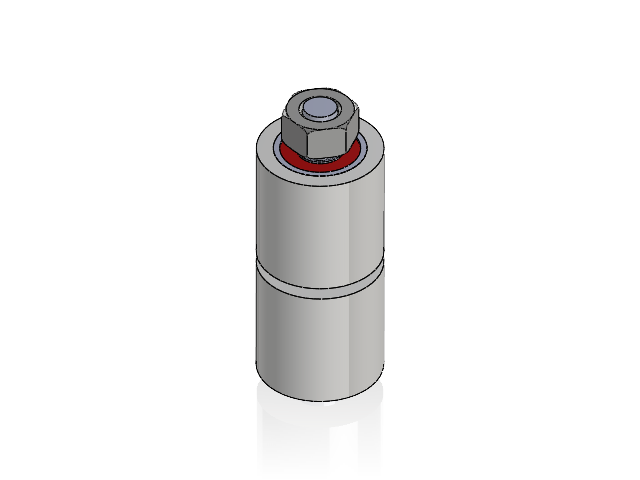
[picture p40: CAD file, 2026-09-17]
05_CAD/Final_CAD/R_Pair/PLANOS SUBENSAMBLE Y COMPONENTE/parRsolo.SLDASM
Pieza1
rodamiento 8 mm x 2
Pieza3
Pieza5
ISO 4032 Nut M10.step
Pieza6sep x 2
Pieza4

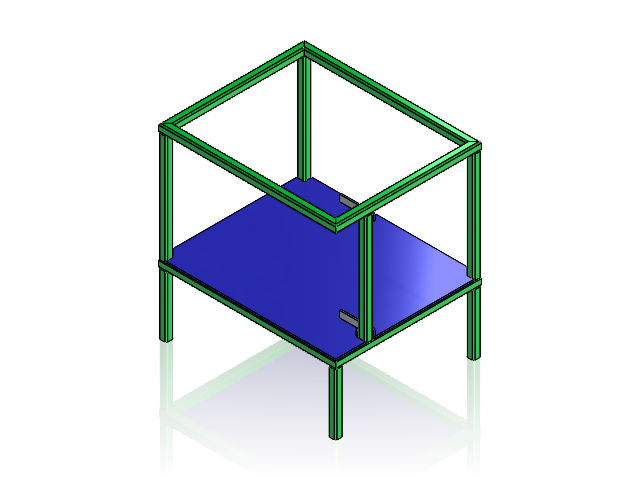
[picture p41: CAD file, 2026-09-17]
05_CAD/Final_CAD/Machine/Maquina/Mesa-Lámina.SLDASM
Mesa_Estructural
LáminaCuartoDePulgadaMesa
Soporte1Top x 2

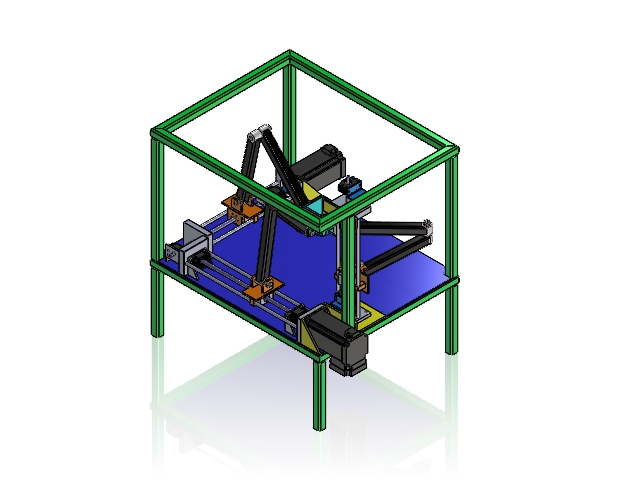
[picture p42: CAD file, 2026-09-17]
05_CAD/Final_CAD/Machine/Maquina/MáquinaCompleta.SLDASM
Mesa_Estructural
LáminaOctavoDePulgadaMesa
Soporte1Top x 2
SoporteMotores x 2
Nema34Closeloop x 3
Lamina-CuartoDePulgada
guia 2
guia 3
guia 1
carrito guia x 3
AT_ACOPLE x 3
AT_BF10 x 3
AT_BK10 x 3
AT_TORNILLOPOTENCIA x 3
CuerpoGuiaTornillo x 3
GuiaTornillos x 3
SoporteLadoMotor x 4
Soporte_Ayuda_TOP
Soporte ayuda 2
Pieza1 x 9
rodamiento 8 mm x 18
Pieza3 x 9
Pieza5 x 3
ISO 4032 Nut M10.step x 9
Pieza6sep x 18
Pieza5tubo x 6
Pieza4 x 3
Eje2 x 6
soporte. diseño de maquinas (1)

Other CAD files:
05_CAD/Final_CAD/R_Pair/cads/EnsamblajeParRCodoPLn.SLDASM
05_CAD/Final_CAD/Machine/PLANOS/EnsamblajeParRCodo.SLDASM
05_CAD/Final_CAD/Machine/Tornillos/acton_622176X20.sldprt
05_CAD/Final_CAD/Machine/Tornillos/acton_622176X40.sldprt
05_CAD/Final_CAD/Machine/Maquina/AT_ACOPLE.SLDPRT
05_CAD/Final_CAD/Machine/Maquina/AT_BF10.SLDPRT
05_CAD/Final_CAD/Machine/Maquina/AT_BK10.SLDPRT
05_CAD/Final_CAD/Machine/Maquina/AT_TORNILLOPOTENCIA.SLDPRT
05_CAD/Final_CAD/Machine/Maquina/BujeGuiaTornillo.SLDPRT
05_CAD/Final_CAD/Machine/Maquina/CuerpoGuiaTornillo.SLDPRT
05_CAD/Final_CAD/Machine/Maquina/GuiaTornillos.SLDPRT
05_CAD/Final_CAD/Machine/Maquina/Intento.SLDPRT
05_CAD/Final_CAD/Machine/Maquina/LáminaOctavoDePulgadaMesa.SLDPRT
05_CAD/Final_CAD/Machine/Maquina/Mesa_Estructural.SLDPRT
05_CAD/Final_CAD/Machine/Maquina/Nema34Closeloop.SLDPRT
05_CAD/Final_CAD/Machine/Maquina/Soporte ayuda 2.SLDPRT
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

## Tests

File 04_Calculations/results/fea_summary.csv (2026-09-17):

quantity | samples | minimum | maximum | mean | abs_max
Bending stress (MPa) | 19 | -9.36 | -0.574 | -3.212 | 9.36
Axial stress (MPa) | 33 | -0.305 | 0.00286 | -0.09252242424242427 | 0.305
Shear stress dir. 1 (MPa) | 40 | -0.987 | 2.69 | 0.1878355 | 2.69
Shear stress dir. 2 (MPa) | 31 | -0.219 | 0.627 | 0.07135548387096777 | 0.627
Strain (-) | 23 | -6.43e-06 | 2.866e-06 | -2.8171411739130434e-07 | 6.43e-06
Displacement (mm) | 22 | 1e-30 | 0.1016 | 0.029171045454545453 | 0.1016
Buckling mode 1, X (mm) | 27 | 0.0 | 0.0285 | 0.011673703703703705 | 0.0285
Buckling mode 1, Y (mm) | 24 | -0.00348 | 0.00345 | 0.0004994083333333333 | 0.00348
Buckling mode 1, Z (mm) | 21 | -0.0213 | 0.00189 | -0.006704619047619048 | 0.0213

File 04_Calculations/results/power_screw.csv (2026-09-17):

case | load_N | lead_mm | dm_mm | dr_mm | lead_angle_deg | T_raise_thread_Nmm | T_lower_thread_Nmm | T_collar_Nmm | T_raise_Nmm | T_lower_Nmm | efficiency | mu_required_for_self_locking | self_locking | motor_torque_ratio | area_mm2 | sigma_axial_MPa | tau_torsion_MPa | tau_thread_MPa | sigma_bearing_MPa | sigma_vonMises_MPa | safety_factor_yield | buckling_I_mm4 | buckling_area_mm2 | buckling_radius_gyration_mm | buckling_slenderness | buckling_slenderness_limit | buckling_P_euler_N | buckling_P_johnson_N | buckling_P_critical_N | buckling_safety_factor
design load from the static analysis | 161.99261990446428 | 8.0 | 7.0 | 6.0 | 19.990512792909144 | 311.92289118881627 | -111.88834727804651 | 9.719557194267857 | 321.6424483830841 | -102.16879008377865 | 0.641256807534188 | 0.3513871312320655 | False | 0.07147609964068535 | 28.274333882308138 | 5.729316933822677 | 7.58384971382928 | 3.7692874564622874 | 1.2277107715334306 | 14.330715333647259 | 25.818669297775564 | 63.61725123519331 | 28.274333882308138 | 1.5 | 333.3333333333333 | 105.08704528448932 | 519.882241098587 | -42167.2687081848 | 519.882241098587 | 3.209295839558551
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

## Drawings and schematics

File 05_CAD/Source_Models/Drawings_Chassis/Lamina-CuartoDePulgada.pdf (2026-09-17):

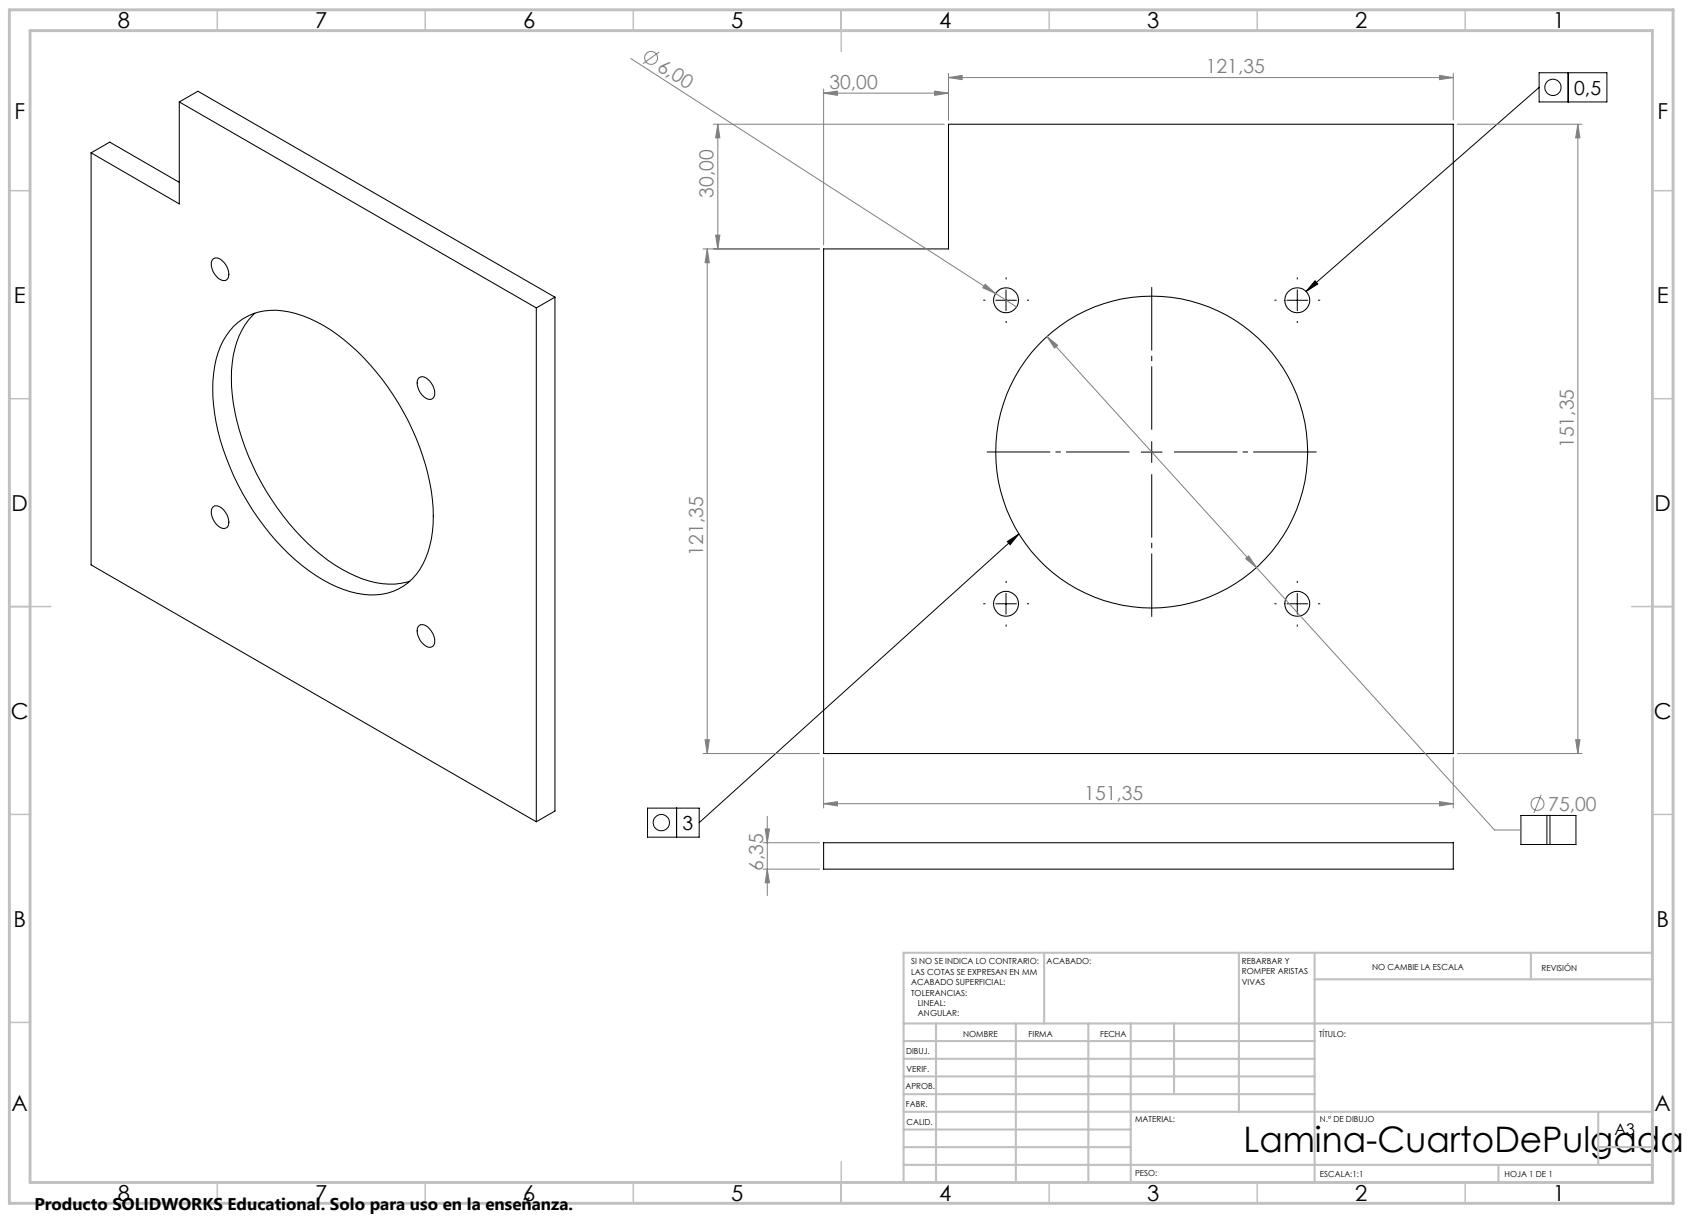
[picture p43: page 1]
ACABADO:; REBARBAR Y; ROMPER ARISTAS; NO CAMBIE LA ESCALA; REVISIÓN; ESCALA:1:1; HOJA 1 DE 1

SI NO SE INDICA LO CONTRARIO:
LAS COTAS SE EXPRESAN EN MM
ACABADO SUPERFICIAL:
TOLERANCIAS:
LINEAL:
ANGULAR:

NOMBRE | FIRMA | FECHA | | | | TÍTULO:

DIBUJ.
VERIF.
APROB.
FABR.
CALID. | | | | MATERIAL: | N.º DE DIBUJO | A3

Producto SOLIDWORKS Educational. Solo para uso en la enseñanza.

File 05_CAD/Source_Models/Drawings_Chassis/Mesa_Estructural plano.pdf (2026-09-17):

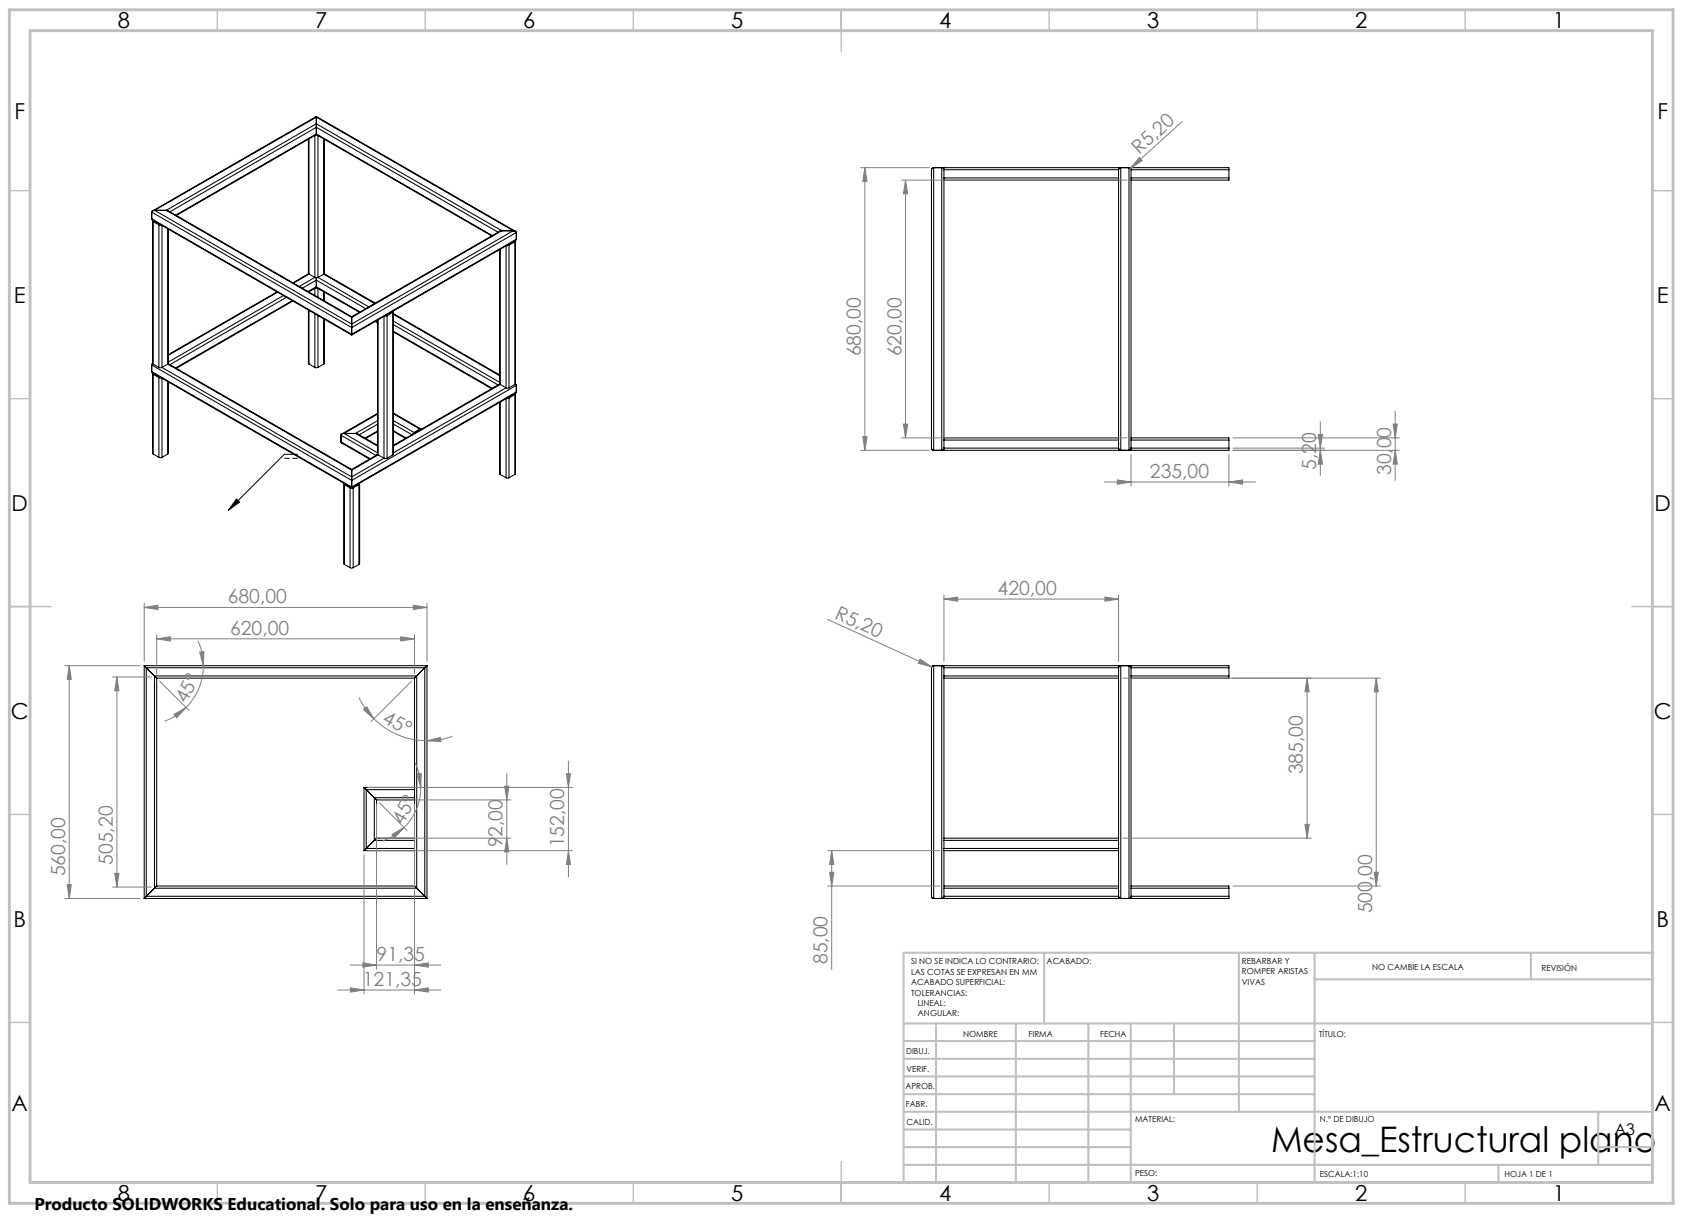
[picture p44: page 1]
ACABADO:; REBARBAR Y; ROMPER ARISTAS; NO CAMBIE LA ESCALA; REVISIÓN; ESCALA:1:10; HOJA 1 DE 1

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

NOMBRE | FIRMA | FECHA | | | | TÍTULO:

DIBUJ.
VERIF.
APROB.
FABR.
CALID. | | | | MATERIAL: Mesa_Estructural plano | N.º DE DIBUJO | A3

Producto SOLIDWORKS Educational. Solo para uso en la enseñanza.

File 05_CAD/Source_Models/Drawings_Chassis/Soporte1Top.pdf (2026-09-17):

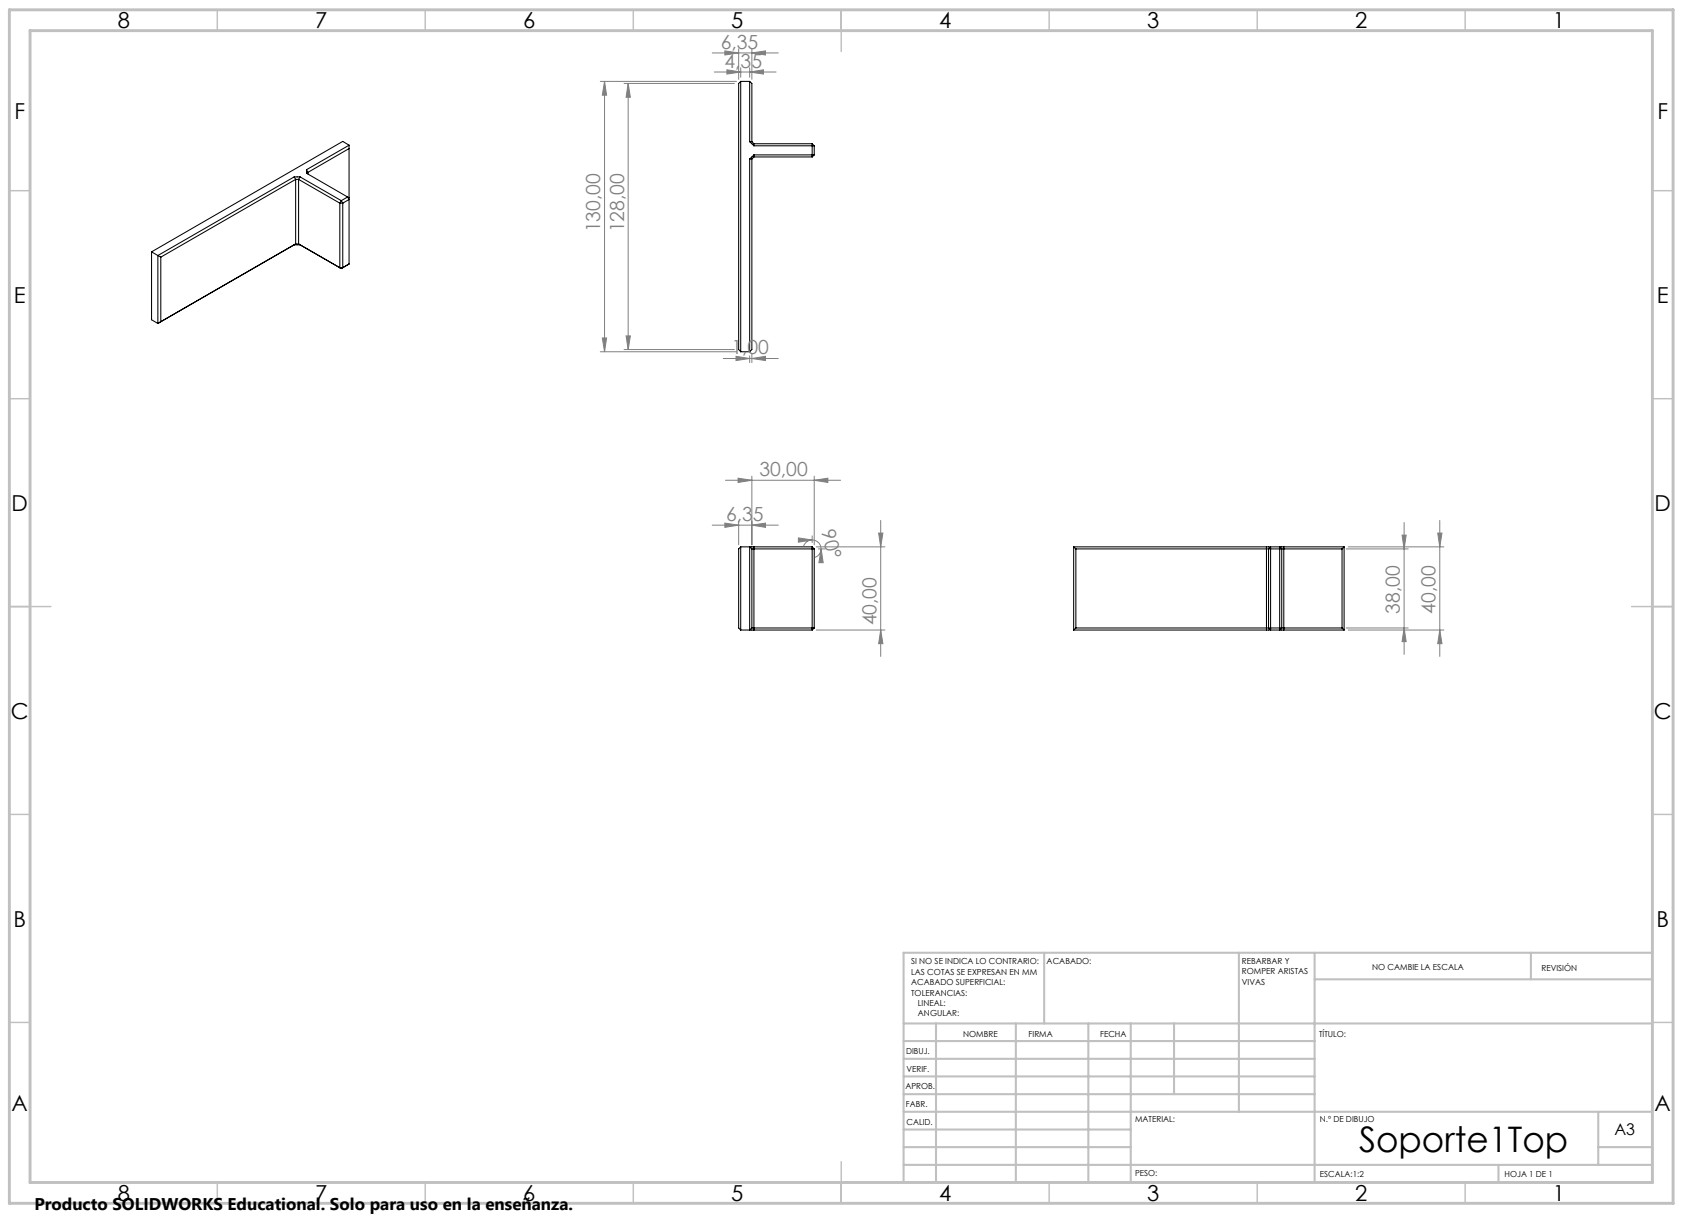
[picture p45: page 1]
ACABADO:; REBARBAR Y; ROMPER ARISTAS; NO CAMBIE LA ESCALA; REVISIÓN; ESCALA:1:2; HOJA 1 DE 1

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

NOMBRE | FIRMA | FECHA | | | | TÍTULO:

DIBUJ.
VERIF.
APROB.
FABR.
CALID. | | | | MATERIAL: | N.º DE DIBUJO Soporte1Top | A3

Producto SOLIDWORKS Educational. Solo para uso en la enseñanza.

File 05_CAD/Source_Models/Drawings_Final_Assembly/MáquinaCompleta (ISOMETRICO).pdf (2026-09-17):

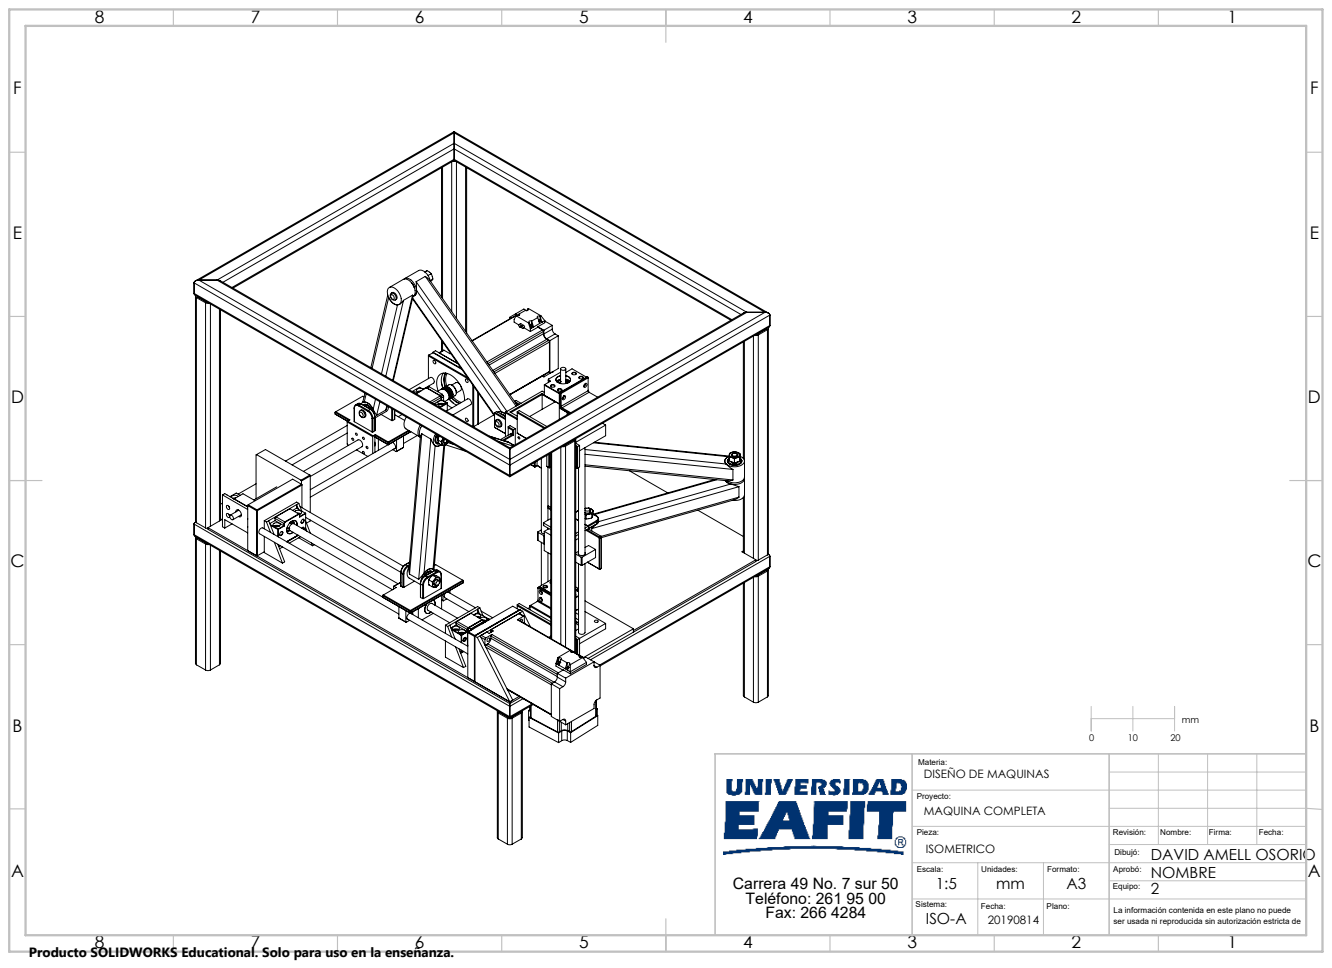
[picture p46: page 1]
Plano:; La información contenida en este plano no puede; DAVID AMELL OSORIO

Carrera 49 No. 7 sur 50 Teléfono: 261 95 00 Fax: 266 4284 | Materia: DISEÑO DE MAQUINAS

Proyecto: MAQUINA COMPLETA

Pieza: ISOMETRICO | Revisión: | Nombre: | Firma: | Fecha:

ser usada ni reproducida sin autorización estricta de

Producto SOLIDWORKS Educational. Solo para uso en la enseñanza.

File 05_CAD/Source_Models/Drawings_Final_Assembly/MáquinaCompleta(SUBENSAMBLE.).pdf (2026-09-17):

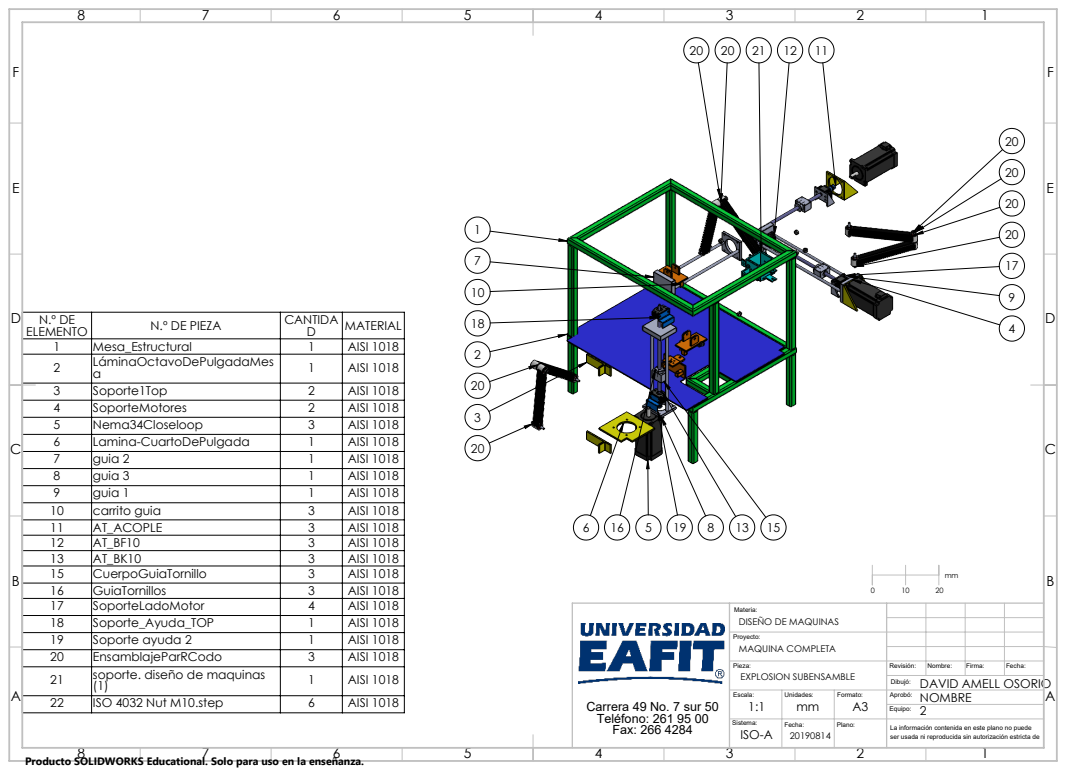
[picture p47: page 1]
Soporte ayuda 2; AISI 1018; ISO 4032 Nut M10.step; AISI 1018 A; Plano:; La información contenida en este plano no puede; MAQUINA COMPLETA; EXPLOSION SUBENSAMBLE; DAVID AMELL OSORIO

ELEMENTO N.º DE | N.º DE PIEZA | CANTIDA D | MATERIAL
1 | Mesa_Estructural | 1 | AISI 1018
2 | LáminaOctavoDePulgadaMes a | 1 | AISI 1018
3 | Soporte1Top | 2 | AISI 1018
4 | SoporteMotores | 2 | AISI 1018
5 | Nema34Closeloop | 3 | AISI 1018
6 | Lamina-CuartoDePulgada | 1 | AISI 1018
7 | guia 2 | 1 | AISI 1018
8 | guia 3 | 1 | AISI 1018
9 | guia 1 | 1 | AISI 1018
10 | carrito guia | 3 | AISI 1018
11 | AT_ACOPLE | 3 | AISI 1018
12 | AT_BF10 | 3 | AISI 1018
13 | AT_BK10 | 3 | AISI 1018
15 | CuerpoGuiaTornillo | 3 | AISI 1018
16 | GuiaTornillos | 3 | AISI 1018
17 | SoporteLadoMotor | 4 | AISI 1018
18 | Soporte_Ayuda_TOP | 1 | AISI 1018

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

20 | EnsamblajeParRCodo | 3 | AISI 1018
21 | soporte. diseño de maquinas (1) | 1 | AISI 1018

ser usada ni reproducida sin autorización estricta de

Producto SOLIDWORKS Educational. Solo para uso en la enseñanza.

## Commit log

2026-09-17 Tripteron CNC router: corrected deliverables and full recomputation of the calculations
    - Delivery 1: design proposal rewritten in English; mobility corrected to the spatial
    Kutzbach criterion (over-constrained, M = 3 translations); PDS units fixed.
    - Delivery 2: English cover and drawing index added in front of the 41 CAD sheets.
    - Delivery 3: calculation report rebuilt from scratch in the course calculation-sheet
    format. Kinematics, statics, lead screw and chassis FEA recomputed with a Python
    package; every result cross-checked by two independent methods.
    - Errors of the previous memo listed and corrected (efficiency > 1, thread shear of
    2380 MPa, Euler formula with E = 20 GPa, zer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
    [Base.SLDPRT, Caja sistema elecrico.SLDDRW, Caja sistema elecrico.SLDPRT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]
2026-09-17 Add the final CAD models extracted from the archives
    05_CAD/Final_CAD holds the SolidWorks parts and assemblies of the machine as built;
    the .zip/.rar exports they came from stay untracked. Mark STEP/IGES as binary.
    [AT_ACOPLE.SLDPRT, AT_BF10.SLDPRT, AT_BK10.SLDPRT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]
2026-09-18 Restore the full group of seven authors, add the guide calculation sheet, use the original 2024 dates
    - All seven members of Group 2 are credited again, and every calculation sheet carries
    the analyst of the original submission (kinematics: Amell/Zuluaga; statics:
    Rodriguez/Rincon; lead screw: Garcia/Zuluaga/Riano; guides: Bueno/Riano/Zuluaga;
    chassis FEA: Zuluaga). Delivery 1 shows the seven individual concepts again and the
    distribution of the work; Delivery 2 lists the draughtsman of every sheet.
    - New Sheet 4, R-pair guides: the original sheet with that title repeated the lead-screw
    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
    [AT_ACOPLE.SLDPRT, AT_BF10.SLDPRT, AT_BK10.SLDPRT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]
2026-09-18 Rebuild the drawing package from the retouched sheets, add the original FEA plots, deduplicate the CAD
    - Delivery 2 is now a generated package: English cover and index plus one landscape page
    per sheet, built from 02_Delivery2_Drawings/sheets/. Thirteen sheets (the whole chassis
    group and the whole electrical group) were redrawn with English title blocks and notes;
    the other twenty-two are reproduced as issued on 3 March 2024. The index gives drawing
    number, scale, draughtsman and status for each.
    - Delivery 1 gains the retouched functional structure, the morphological matrix and the
    evaluation matrix of the concepts.
    - Sheet 5 of the calculation report now carries the eleven origi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
    [AT_ACOPLE.SLDPRT, AT_BF10.SLDPRT, AT_BK10.SLDPRT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]
